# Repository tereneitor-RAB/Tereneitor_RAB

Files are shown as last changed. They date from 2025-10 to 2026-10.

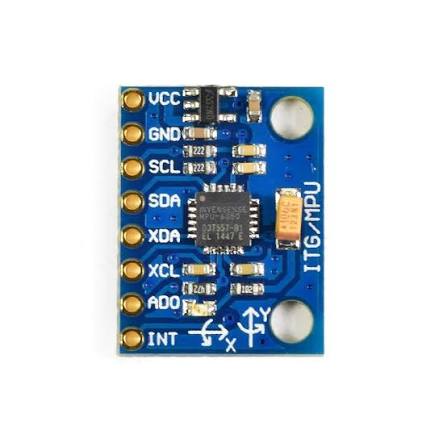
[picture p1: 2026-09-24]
Parts listo/Modulo MPU6050.jpg

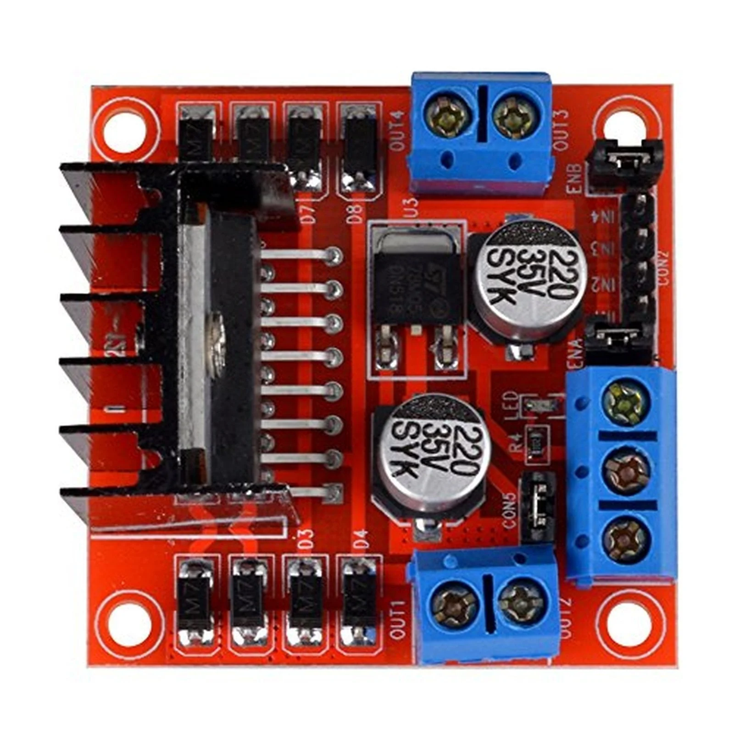
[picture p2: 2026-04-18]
Parts listo/modulo de motor.webp

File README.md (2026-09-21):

# Tereneitor_RAB| Future Engineers | Puerto Rico🚀

## Competitors of this team
- Daniel Rafael Roman Rodriguez - 19 years old
- Luis Rios Santos - 19 years old
  WhatsApp Image 2026-04-30 at 2 58 54 PM

## Robot image
WhatsApp Image 2026-09-17 at 12 14 56 AM

## Content 📘
| Folder  | content |
| -- | -- |
| [Parts listo](https://github.com/tereneitor-RAB/Tereneitor_RAB/tree/main/Parts%20listo)| [Camera 2.1V](https://github.com/tereneitor-RAB/Tereneitor_RAB/blob/main/Parts%20listo/Camera.webp) [Chasis](https://github.com/tereneitor-RAB/Tereneitor_RAB/blob/main/Parts%20listo/Chasis%20.png) [Motor DC](https://github.com/tereneitor-RAB/Tereneitor_RAB/blob/main/Parts%20listo/Motor%20DC.png) [Servo motor](https://github.com/tereneitor-RAB/Tereneitor_RAB/blob/main/Parts%20listo/Servo%20Motor.png) [Abilix engine](https://github.com/tereneitor-RAB/Tereneitor_RAB/blob/main/Parts%20listo/abilix%20engine.jpeg) [Abilix gums](https://github.com/tereneitor-RAB/Tereneitor_RAB/blob/main/Parts%20listo/abilix%20gums.jpeg) [Bateria 14V](https://github.com/tereneitor-RAB/Tereneitor_RAB/blob/main/Parts%20listo/bateria%2014v.webp) [differentiator](https://github.com/tereneitor-RAB/Tereneitor_RAB/blob/main/Parts%20listo/differentiator.jpeg) [modulo motor](https://github.com/tereneitor-RAB/Tereneitor_RAB/blob/main/Parts%20listo/modulo%20de%20motor.webp) [disminulle voltaje](https://github.com/tereneitor-RAB/Tereneitor_RAB/blob/main/Parts%20listo/modulo%20que%20disminulle%20el%20voltaje.jpg) [raspberry pi 4B](https://github.com/tereneitor-RAB/Tereneitor_RAB/blob/main/Parts%20listo/raspberry%20pi%204%20B.jpg) [touch screen](https://github.com/tereneitor-RAB/Tereneitor_RAB/blob/main/Parts%20listo/touch%20screen.jpg) [Lidar D500](https://github.com/tereneitor-RAB/Tereneitor_RAB/blob/main/Parts%20listo/Lidar%20D500.jpg)
| [Team Photos](https://github.com/tereneitor-RAB/Tereneitor_RAB/tree/main/Team%20Photos)|[foto de equipo](https://github.com/tereneitor-RAB/Tereneitor_RAB/blob/main/Team%20Photos/Foto%20de%20equipo.jpeg) [foto de equipo](https://github.com/tereneitor-RAB/Tereneitor_RAB/blob/main/Team%20Photos/foto%20del%20equipo.jpeg)
|[Vehicle Photos](https://github.com/tereneitor-RAB/Tereneitor_RAB/tree/main/photos%20of%20the%20car)|[Photos 1](https://github.com/tereneitor-RAB/Tereneitor_RAB/blob/main/photos%20of%20the%20car/Photo%201.jpg) [photos 2](https://github.com/tereneitor-RAB/Tereneitor_RAB/blob/main/photos%20of%20the%20car/photo%202.jpg) [photos 3](https://github.com/tereneitor-RAB/Tereneitor_RAB/blob/main/photos%20of%20the%20car/photo%203.jpg) [photos 4](https://github.com/tereneitor-RAB/Tereneitor_RAB/blob/main/photos%20of%20the%20car/photo%204.jpg) [photos 5](https://github.com/tereneitor-RAB/Tereneitor_RAB/blob/main/photos%20of%20the%20car/photo%205.jpg) [Photos 6](https://github.com/tereneitor-RAB/Tereneitor_RAB/blob/main/photos%20of%20the%20car/photo%206.jpg)|
|[src](https://github.com/tereneitor-RAB/Tereneitor_RAB/tree/main/src)|[Free track programming](https://github.com/tereneitor-RAB/Tereneitor_RAB/blob/main/src/Programacion%20pista%20libre.py)|
|[Videos](https://github.com/tereneitor-RAB/Tereneitor_RAB/tree/main/Videos)|[Test 1](https://github.com/tereneitor-RAB/Tereneitor_RAB/blob/main/Videos/Test%201.mp3) [Test 2](https://github.com/tereneitor-RAB/Tereneitor_RAB/blob/main/Videos/Test%202.mp3) [Test 3](https://github.com/tereneitor-RAB/Tereneitor_RAB/blob/main/Videos/Test%203.mp3)|

| project  |
| -- |
|[mount start](https://github.com/users/tereneitor-RAB/projects/1)|
|[Regional March 28](https://github.com/users/tereneitor-RAB/projects/5)|
|[regional April 18](https://github.com/users/tereneitor-RAB/projects/7)|
|[preparation for the national](https://github.com/users/tereneitor-RAB/projects/8)|
|[preparation for the California Open Championship](https://github.com/users/tereneitor-RAB/projects/10)|

------------------------------------------------------------

 #  [Our YouTube Channel](https://www.youtube.com/@Tereneitor_RedandBlue/videos)

- On our YouTube channel, we have videos of regional, national, and recent competitions to document all the processes we've undertaken over time.

------------------------------------------------------------

# WHAT IS THIS CATEGORY ABOUT❓


- This is the track for this category in 2026, on this track there are 2 modes, free mode and obstacle mode. In free mode only the robot will have to make 3 laps and stop after completing the 3 laps. In obstacle mode the robot has to make 3 laps while avoiding the obstacles and after making 3 laps it will have to parallel park.

- The obstacles are placed by the Judge and he is the one who assigns the parking spot. Both the obstacles and the parking spot are at the discretion of the Judge, so it is completely random.

- If the robot hits a wall the Judge stops counting the time and when he indicates the robot can be picked up.

- The walls in the center of the court can vary in size.

- This category may be similar to autonomous robots that are sent into space to explore planets, since they must avoid any object that gets in their way and also explore and send information about the planet.
WRO provides us with the official rules for this category of Future Engineers.

- [Official rules](https://wro-association.org/wp-content/uploads/WRO-2026-Future-Engineers-Self-Driving-Cars-General-Rules.pdf)
-------------------------------------------------------------------------

# [Explanation of the programming](https://github.com/tereneitor-RAB/Tereneitor_RAB/tree/main/src#readme)

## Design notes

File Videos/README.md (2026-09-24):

# Attached to this folder are the videos of the robot's track tests

---------------------------------------
## [youtube channel](https://www.youtube.com/@Tereneitor_RedandBlue/videos)
---------------------------------------

### **Free track tests**
- #### Test 1

https://github.com/user-attachments/assets/691180ef-8aa6-4b70-8443-ffb057dd5ace

- #### Test 2

https://github.com/user-attachments/assets/205f8fcf-265c-48af-8374-0597f4ce6e7e

- #### Test 3

https://github.com/user-attachments/assets/8cd0d115-da4b-45ae-adf6-b096099adb8a

---------------------------------------

### Obstacle course tests
- #### Test 1

https://github.com/user-attachments/assets/fc7ae0b0-fefc-44e3-b8f4-92074570e415

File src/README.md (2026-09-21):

# Attached to this folder is the robot's programming and an explanation of the programming.

# explanation of robot programming

- The robot's programming is designed to allow it to navigate the track autonomously using different sensors and control systems.

- The **D500 LiDAR** is the main sensor used to detect walls and measure the distances around the robot. The program divides the surrounding area into different zones, such as front, left, right, and diagonal sections, so the robot can determine where there is available space and make decisions when it encounters a wall.

- The **Raspberry Pi camera** is mainly used to detect red and green obstacles. The image is processed using OpenCV, and only a horizontal section of the image is analyzed to reduce unnecessary processing.

- The **steering servo** controls the direction of the robot. To prevent sudden movements, the program uses different movement speeds depending on how far the servo is from its target position. This makes the steering changes smoother.

- While moving, the robot also tries to maintain a distance of approximately **550 mm from the selected wall**. The program makes small steering corrections when the robot gets too close or too far from that wall.

- When the robot detects a wall in front of it, the program analyzes different areas on both the left and right sides before deciding which direction to take. Instead of looking at only one point, it considers the side, diagonal, and near-front areas.

- Every time a new turn begins, the program increases the turn counter. The limit is set to **12 turns**. Once the robot reaches the 12th turn, it stops the motor, centers the servo, and shuts down the steering system.
The program also includes an **emergency reverse system**. If the LiDAR detects that a wall is too close, the robot stops, reverses, and checks the available space again before continuing.

- The robot starts after the start button is pressed. While waiting, the green LED stays on to indicate that the system is ready. Once the button is pressed, the motor starts moving and the program enters its main navigation loop.

- During the run, the program displays the camera feed and a **360° LiDAR radar**, along with the front, left, and right distances, detected color, number of turns completed, and the current servo position.

- Overall, the program combines the **LiDAR for navigation**, the **camera for color-based obstacle detection**, and the **servo and motor for movement**. This allows the robot to make decisions while navigating the track without manual control.

---------------------------------------------------------------------------

# Operating System Installation – Raspberry Pi 4B

Before starting the project, the Raspberry Pi 4B needs an operating system. For this project, **Raspberry Pi OS** is installed on a microSD card using **Raspberry Pi Imager**.

## 1. Download Raspberry Pi Imager

Download and install **Raspberry Pi Imager** on a computer from the official Raspberry Pi website:

[**Download Raspberry Pi Imager**](https://www.raspberrypi.com/software/)

Then connect the microSD card to the computer using a card reader.

## 2. Select the Raspberry Pi

Open Raspberry Pi Imager and select:

* **Device:** Raspberry Pi 4
* **Operating System:** Raspberry Pi OS
* **Storage:** The connected microSD card

> [!IMPORTANT]
> The microSD card will be erased during the installation. Make sure the correct card is selected.

## 3. Configure the System

Before writing the operating system, Raspberry Pi Imager allows you to configure some basic settings, such as:

* Username and password
* Wi-Fi connection
* Time zone
* Keyboard layout
* Hostname

These settings make the Raspberry Pi ready to use after the first boot.

## 4. Install the Operating System

After checking the configuration:

1. Click **Next** or **Write**.
2. Confirm that the microSD card can be erased.
3. Wait while Raspberry Pi Imager writes the operating system.
4. Wait for the verification process to finish.

This may take several minutes.

## 5. Start the Raspberry Pi

When the installation is complete:

1. Safely eject the microSD card.
2. Insert it into the Raspberry Pi 4B.
3. Connect the monitor, keyboard, and mouse if needed.
4. Connect the power supply.
5. Wait for Raspberry Pi OS to start.

Complete any remaining initial configuration.

## 6. Update the System

Open the terminal and run:

```bash
sudo apt update
sudo apt full-upgrade -y
```

Then restart the Raspberry Pi:

```bash
sudo reboot
```

## 7. Verify the Installation

To check the operating system, run:

```bash
cat /etc/os-release
```

If the Raspberry Pi OS information is displayed correctly, the installation is complete.

----------------------------------------------------------------------------

# Required Libraries Installation

After installing Raspberry Pi OS, the next step is to install the Python libraries required by the robot.

## 1. Update the System

First, update the package list:

```bash
sudo apt update
sudo apt full-upgrade -y
```

## 2. Install Python and Basic Tools

Install Python and the required development tools:

```bash
sudo apt install -y python3 python3-pip python3-dev
```

## 3. Install OpenCV

OpenCV is used for image processing and detecting colors and objects with the Raspberry Pi Camera.

```bash
sudo apt install -y python3-opencv
```

Verify the installation:

```bash
python3 -c "import cv2; print(cv2.__version__)"
```

## 4. Install Picamera2

Picamera2 is used to control the Raspberry Pi Camera.

```bash
sudo apt install -y python3-picamera2
```

Verify the installation:

```bash
python3 -c "from picamera2 import Picamera2; print('Picamera2 OK')"
```

## 5. Install GPIO Libraries

The GPIO pins are used to control the button, LEDs, motor driver, and servo.

Install RPi.GPIO:

```bash
sudo apt install -y python3-rpi.gpio
```

If the project uses GPIO Zero, it can also be installed with:

```bash
sudo apt install -y python3-gpiozero
```

## 6. Install PySerial

PySerial is used for serial communication between the Raspberry Pi and the LiDAR D500.

```bash
sudo apt install -y python3-serial
```

Verify the installation:

```bash
python3 -c "import serial; print('PySerial OK')"
```

## 7. Install NumPy

NumPy is used by OpenCV and other parts of the vision system for numerical and image data processing.

```bash
sudo apt install -y python3-numpy
```

Verify the installation:

```bash
python3 -c "import numpy; print(numpy.__version__)"
```

## 8. Install All Main Libraries

The main libraries used by the robot can also be installed together:

```bash
sudo apt install -y python3-opencv python3-picamera2 python3-rpi.gpio python3-gpiozero python3-serial python3-numpy
```

## 9. Test the Main Libraries

Run the following command to check that the main Python libraries can be imported:

```bash
python3 -c "import cv2, serial, numpy; from picamera2 import Picamera2; import RPi.GPIO; print('All main libraries installed successfully')"
```

If the terminal displays:

```text
All main libraries installed successfully
```

the main software dependencies are ready.

- # After downloading the operating system and libraries on the Raspberry Pi 4B, it would be 100% ready to run the programming explained above.

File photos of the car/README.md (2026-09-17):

# Attached to this folder are photos of the robot from different angles.

WhatsApp Image 2026-09-17 at 12 14 56 AM

| Side on which the photo was taken | Photos |
| -- | -- |
| Frontal  | |
| Left side  | |
| Right back | |
| Tracer | |
|  Superior  | |
| Later | |

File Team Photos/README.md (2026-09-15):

# Attached to this folder are photos of the team members
- **photo 1**
WhatsApp Image 2026-04-30 at 2 58 54 PM

- **photo 2**
foto del equipo

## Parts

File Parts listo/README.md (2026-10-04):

# Attached to this folder is the list of parts used by our robot

## 📦 Parts List

|  # | Component | Quantity | Description / Function |
| -: | --- | ---: | --- |
|  1 | Raspberry Pi 4 Model B | 1 | Main computer and control system of the robot |
|  2 | Raspberry Pi Camera V2 | 1 | Vision system used for color and obstacle detection |
|  3 | LDROBOT D500 LiDAR | 1 | Distance sensor used to detect walls, obstacles, and openings |
|  4 | L298N Motor Driver | 1 | Controls the DC motors |
|  5 | Servo Motor | 1 | Controls the steering mechanism |
|  6 | DC Motors | 1 | Provides movement and propulsion |
|  7 | Wheels | 4 | Allows the robot to move around the competition field |
|  8 | Robot Chassis | 1 | Main structural platform of the robot |
|  9 | Battery | 1 | Provides power to the robot's electrical system |
| 10 | Push Button | 1 | Used to start the robot |
| 11 | Green LED | 1 | Indicates that the robot is ready to start |
| 12 | Jumper Wires / Cables  | 16 | Used for electrical and signal connections |
| 13 | Screws and nuts | 56 | Used to mount and secure the components |
| 14 | Camera Mount | 1 | Secures the camera to the robot |
| 15 | thread separators | 12 | to separate and join the parts of the chassis |
| 16 | publisher | 1 | to start programming |
| 17 | MPU 6050 | 1 | Monitor the turns |

## 💲 price of materials purchased

| # | Component | Quantity | Estimated Unit Price (USD) |
|---|---|---|---|
| 1 | Raspberry Pi 4 Model B 4GB | 1 | $75.00 |
| 2 | Raspberry Pi Camera V2 | 1 | $16.50 |
| 3 | LDROBOT D500 LiDAR | 1 | $69.00 
| 4 | L298N Motor Driver | 1 | $5.00 |
| 5 | Servo Motor | 1 | $8.00 |
| 6 | DC Motors | 1 set | $15.00 |
| 7 | Wheels | 4 | $12.00 |
| 8 | Robot Chassis | 1 | $25.00 |
| 9 | Battery | 1 | $30.00 |
| 10 | Push Button | 1 | $0.50 |
| 11 | Green LED | 1 | $0.25 |
| 12 | Jumper Wires / Cables | 16 | $2.00 |
| 13 | Screws and Nuts | 56 | $6.00 |
| 14 | Camera Mount | 1 | $8.00 |
| 15 | Thread Separators | 12 | $5.00 |
| 16 | Publisher / Programming Software | 1 | $0.00 |
| 17 | MPU6050 | 1 | $4.00 |
| 18 | Blue PLA Filament, 1 kg | 1 | $16.90 |
| 19 | Red PLA Filament, 1 kg | 1 | $16.90 |
> **Estimated total project cost: $314.55 USD**

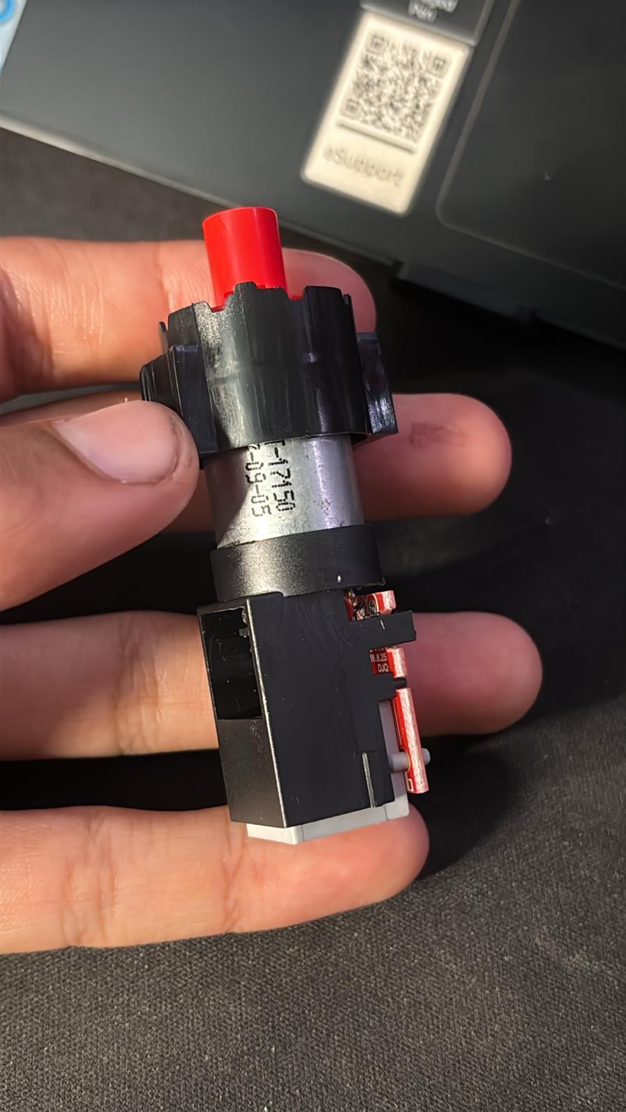
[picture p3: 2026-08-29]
Parts listo/abilix engine.jpeg

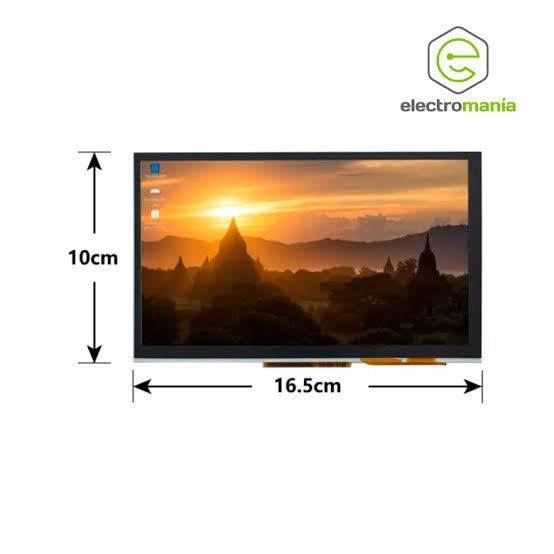
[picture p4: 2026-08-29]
Parts listo/touch screen.jpg

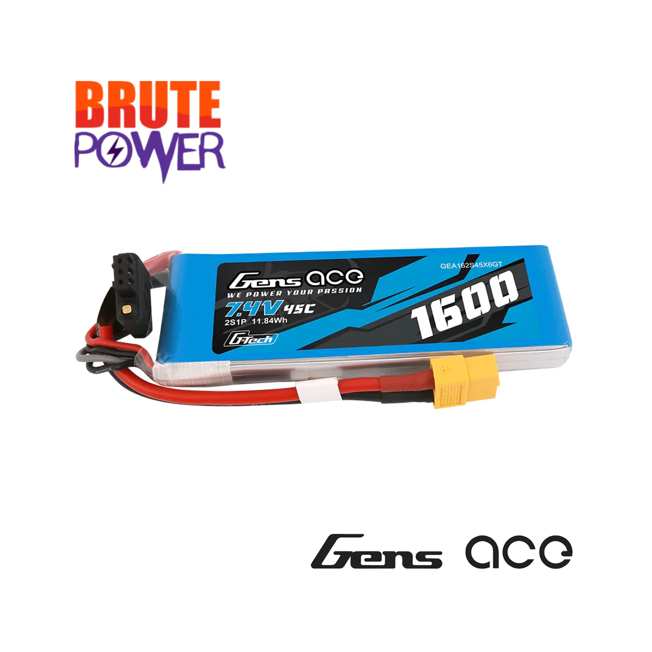
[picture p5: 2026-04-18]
Parts listo/bateria 14v.webp

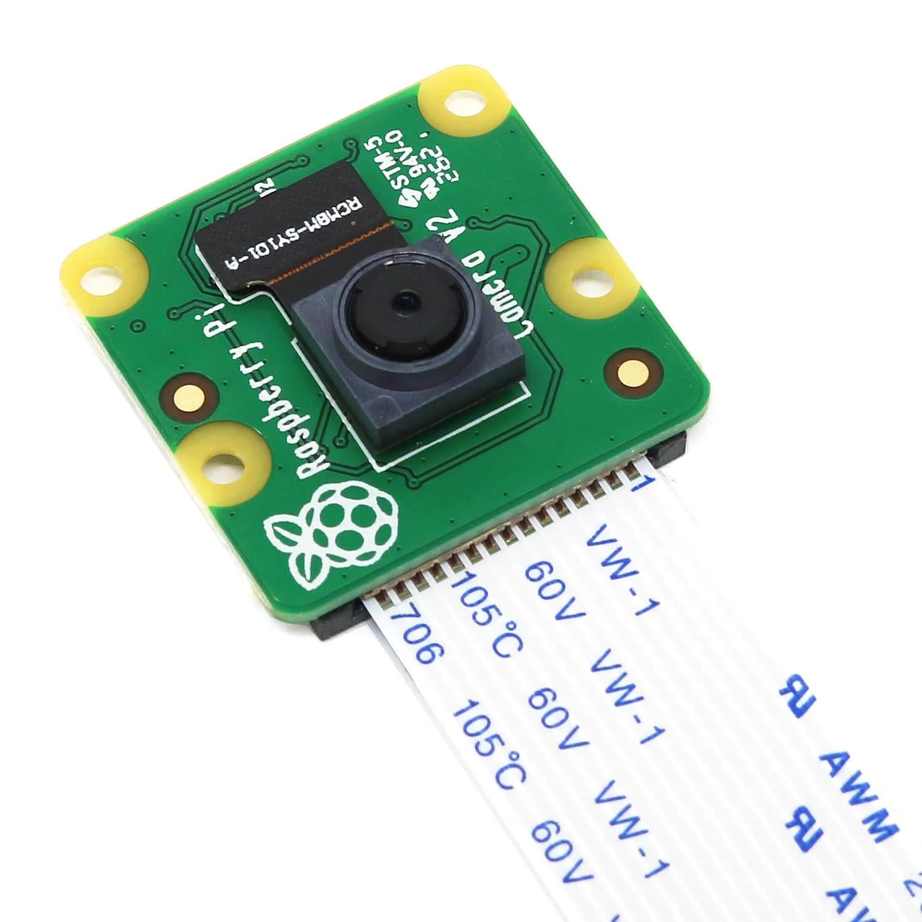
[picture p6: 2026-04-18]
Parts listo/Camera.webp

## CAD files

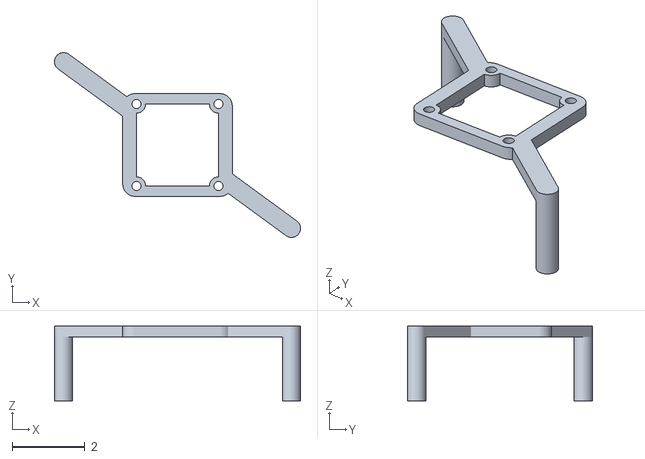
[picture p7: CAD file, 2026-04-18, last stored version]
3D Models listo/avanico.stl
6.75 x 5.07 x 2.05

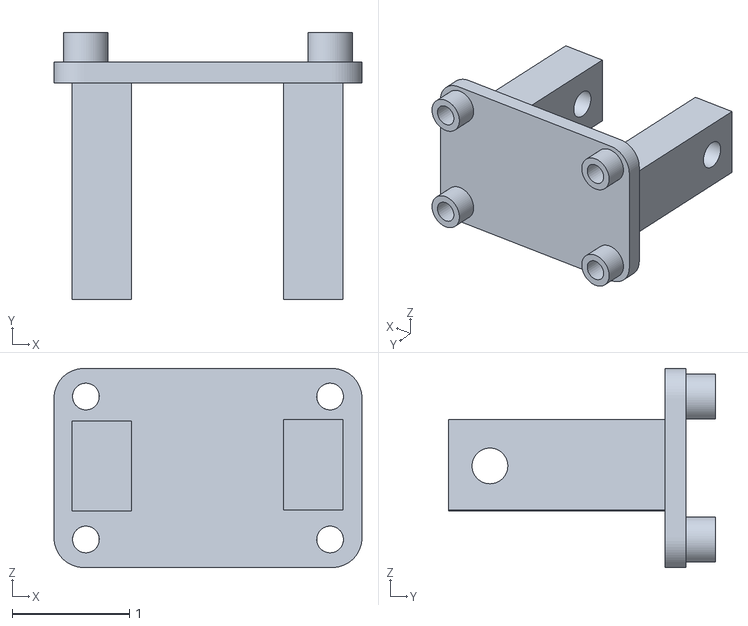
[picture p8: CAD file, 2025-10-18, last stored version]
3D Models/Frame/camera adapter.stl
2.63 x 2.28 x 1.70

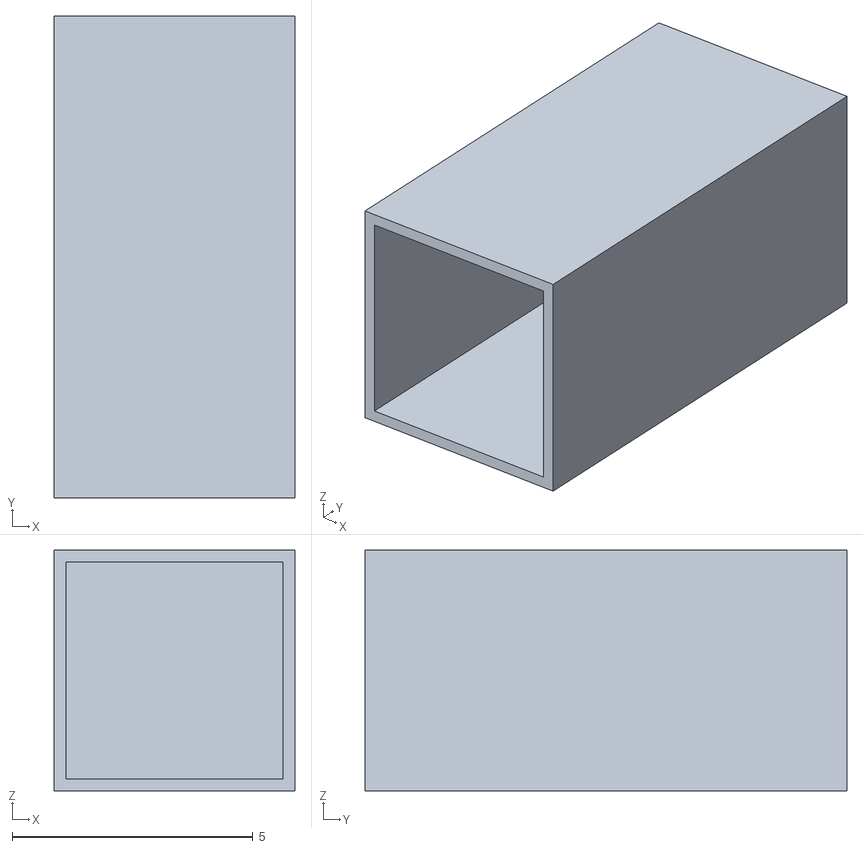
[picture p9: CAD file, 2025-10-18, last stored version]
3D Models/Traffic signs.stl
5.00 x 10.0 x 5.00

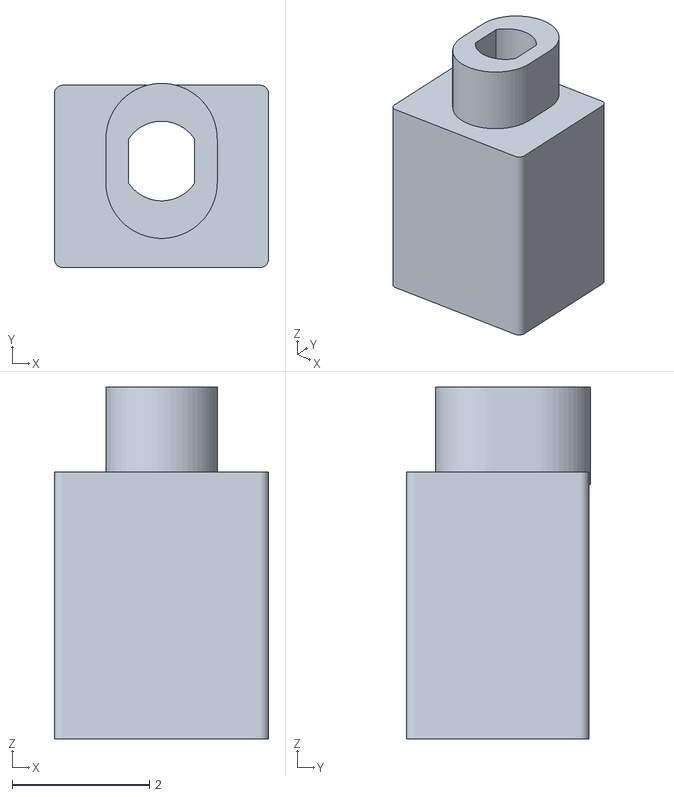
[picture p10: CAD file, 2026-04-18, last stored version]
3D Models listo/base de motor.stl
3.12 x 2.68 x 5.13

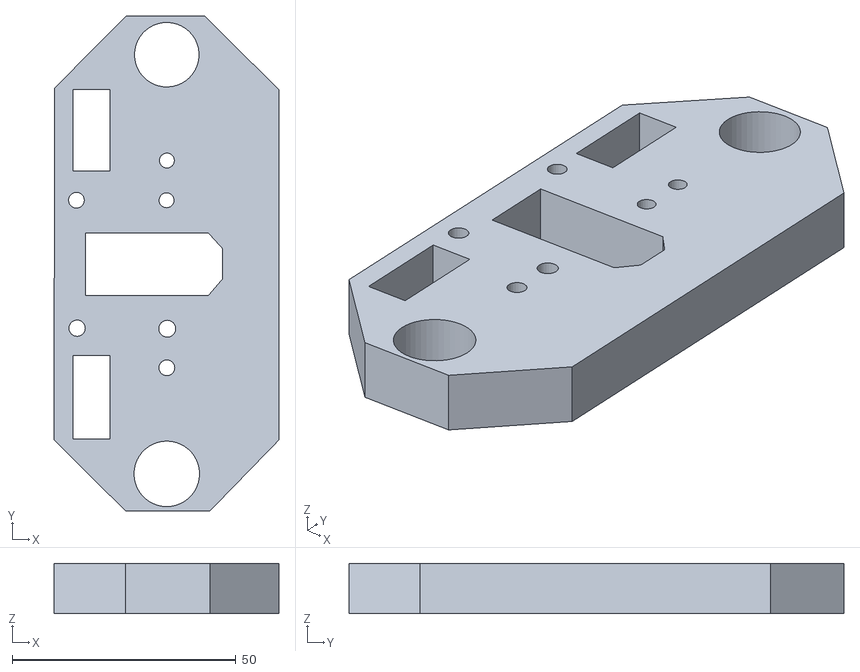
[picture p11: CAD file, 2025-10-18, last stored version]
3D Models/Frame/Model 7.stl
50.3 x 110.7 x 11.2

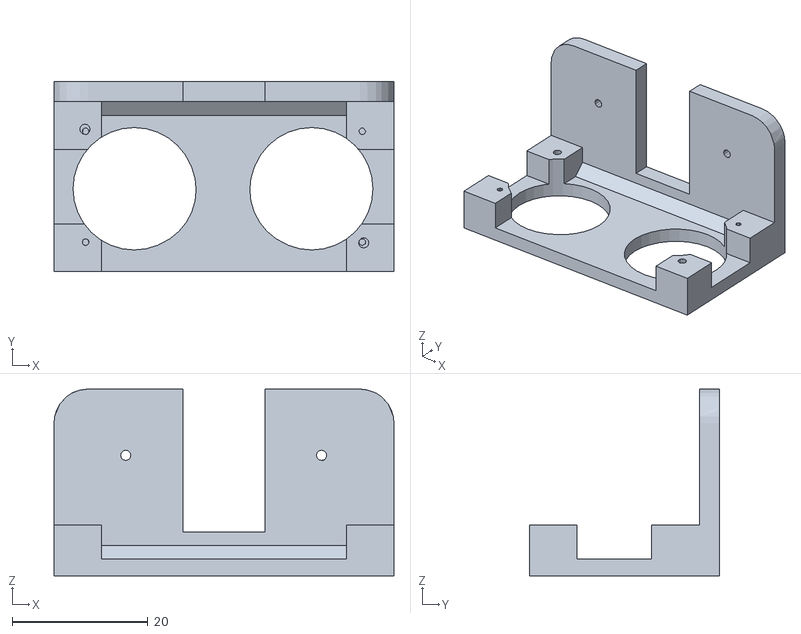
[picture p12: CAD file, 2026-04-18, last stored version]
3D Models listo/Front_ultrasonic_sensor_base.stl
50.0 x 28.0 x 27.5

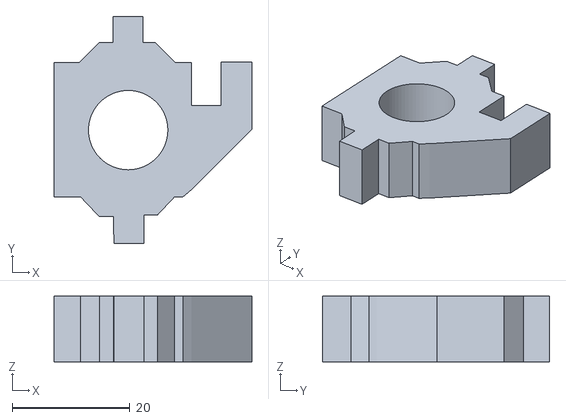
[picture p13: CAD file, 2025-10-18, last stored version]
3D Models/Frame/Model 1.stl
33.6 x 38.6 x 11.2

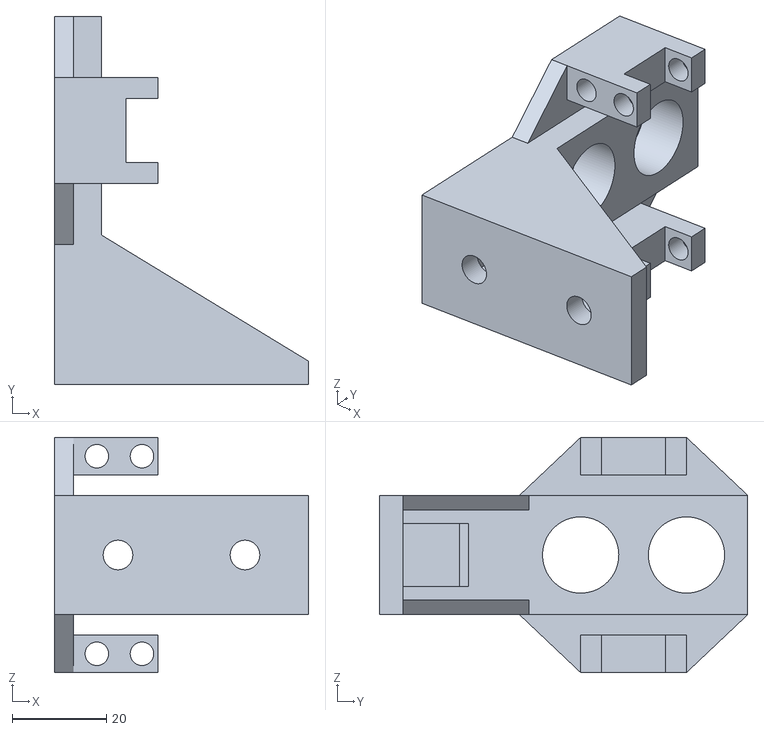
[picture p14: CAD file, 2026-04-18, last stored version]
3D Models listo/Side_Ultrasonic_Sensor_Base.stl
54.0 x 78.3 x 50.0

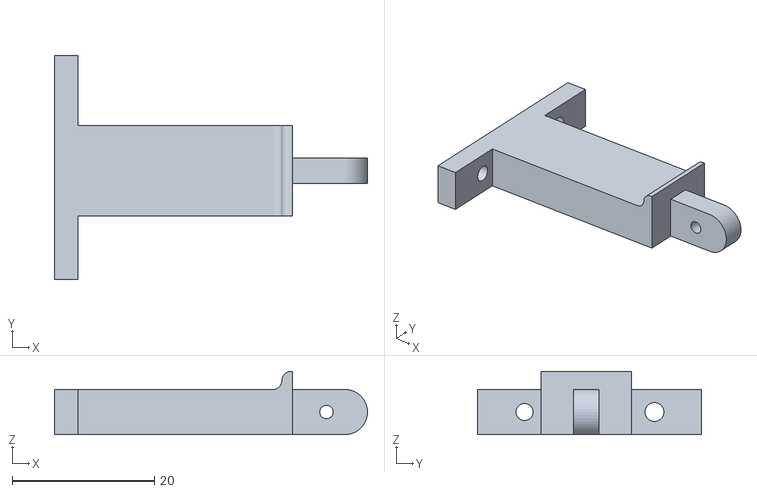
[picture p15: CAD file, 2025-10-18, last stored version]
3D Models/Frame/Model 12.stl
44.1 x 31.5 x 8.89

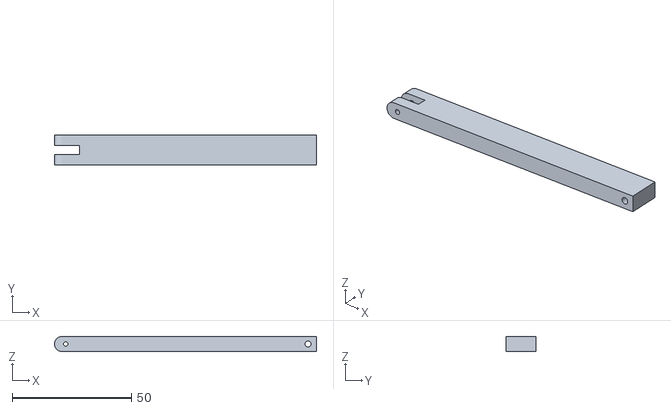
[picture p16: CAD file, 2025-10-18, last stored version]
3D Models/Frame/Model 6.stl
110.0 x 12.7 x 6.35

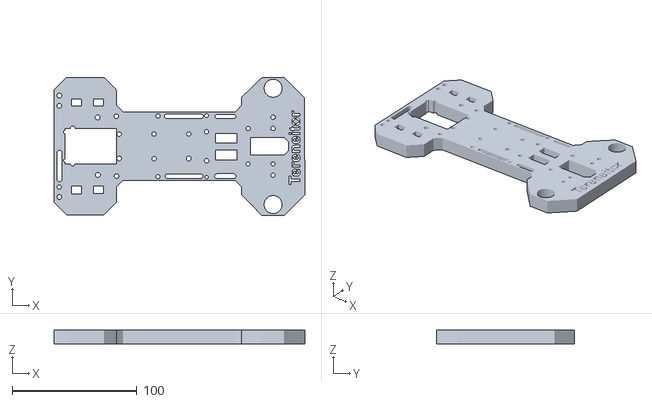
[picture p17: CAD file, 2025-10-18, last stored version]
3D Models/Frame/Model 8.stl
201.3 x 110.9 x 11.2

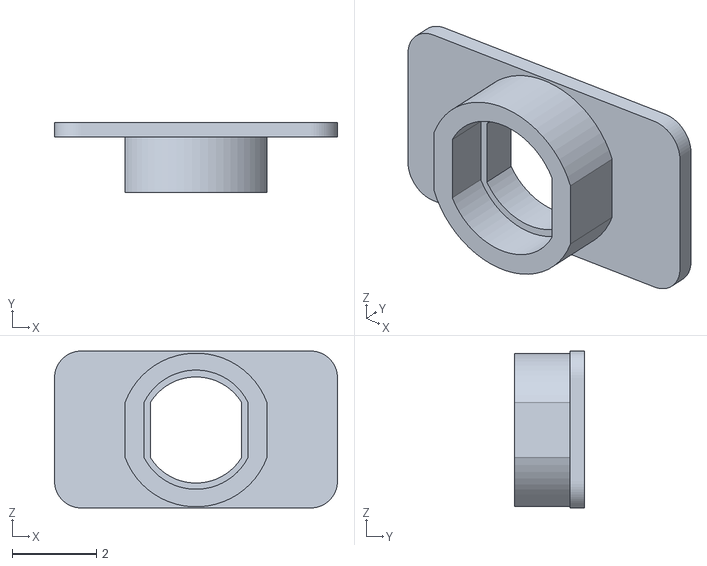
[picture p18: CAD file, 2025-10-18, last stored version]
3D Models/Frame/motor base.stl
6.72 x 1.67 x 3.73

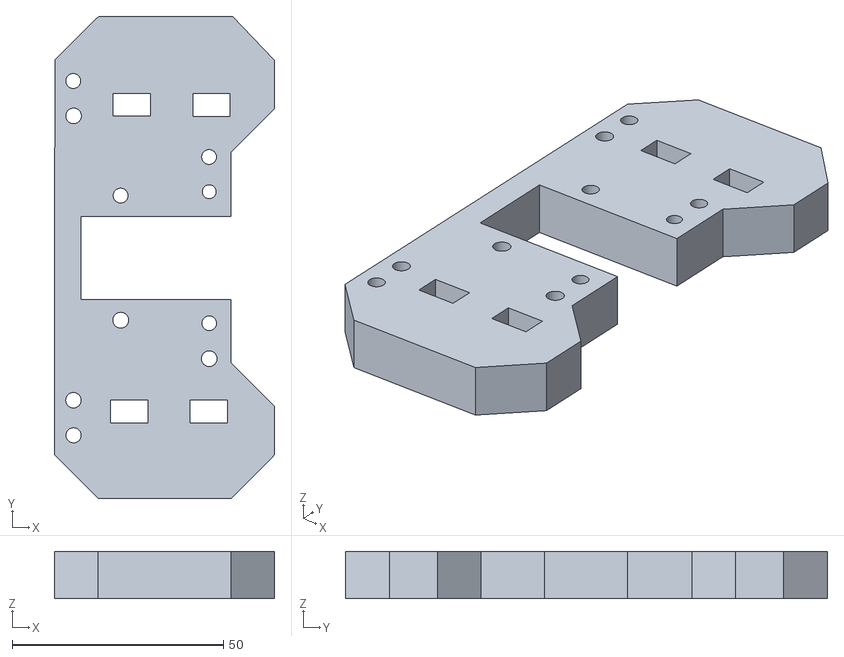
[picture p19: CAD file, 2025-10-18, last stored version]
3D Models/Frame/Model 11.stl
52.1 x 114.0 x 11.2

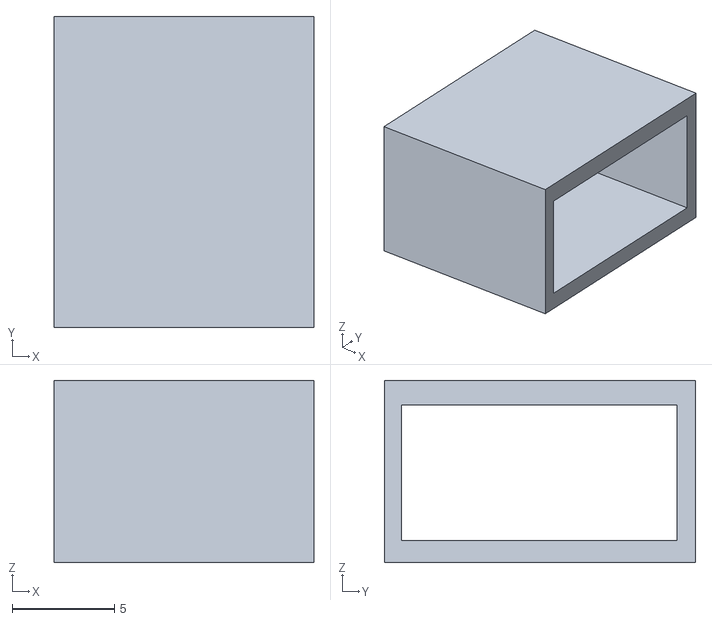
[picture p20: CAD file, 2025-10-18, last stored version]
3D Models/Frame/Model 5.stl
12.7 x 15.2 x 8.90

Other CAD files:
3D Models/Frame/Model 4.stl
3D Models/Frame/Model 2.stl
3D Models/Frame/Model 3.stl
3D Models/Frame/Model 10.stl
3D Models/Frame/Model 9.stl

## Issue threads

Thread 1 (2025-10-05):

presentation of the group Day #1

tereneitor-RAB, 2025-10-05:
Our group is made up of **Daniel, Luis, and Jason**, three students passionate about engineering and technology. We participated in the **WRO Future Engineers** competition with the goal of applying our knowledge, strengthening our skills, and developing an innovative project. Through this work, we seek to proudly represent Puerto Rico and demonstrate our commitment to advancing educational robotics.

Today, October 5, 2025, we will begin assembling a new robot for the WRO Future Engineers competition in 2026, **in which we aim to build upon our experience from 2024, when we competed in the same category and reached the World Championships in Turkey, and once again showcase our skills and innovation with this new robot.**

tereneitor-RAB, 2025-10-05:
**Today we're deciding what kind of robot we want to build**
one that uses sensors or one that works with external cameras. While we make this decision, I, Daniel Roman, will be in charge of documenting everything we do today.

tereneitor-RAB, 2025-10-05:
**After mentioning the weaknesses of each of the options we had, we decided to have the car equipped with a camera, since we can find another solution for the blind spots later on. Another thing is that we have to decide what type of camera and what motherboard runs the image and programming appropriate for this project. As a group, we decided that the car will be equipped with a camera for now.**

_For the moment, we will not work on anything else. The task of each of us is to find what type of chassis we want. We will look for ideas on the Internet and kits that exist and we will let ourselves be guided by those types of chassis. But something that we will have in mind is that the type of chassis must be compatible with a differentiator and front turning mechanism, since the rules emphasize those specifications._

Closed 2025-10-05.

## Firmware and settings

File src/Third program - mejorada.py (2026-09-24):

from picamera2 import Picamera2
import cv2
import numpy as np
import time
import RPi.GPIO as GPIO
import serial
import threading
import math
import os
import smbus2

os.environ["DISPLAY"] = ":0"

# ============================================================
# GPIO
# ============================================================

GPIO.setmode(GPIO.BCM)
GPIO.setwarnings(False)

BOTON = 16
GPIO.setup(BOTON, GPIO.IN, pull_up_down=GPIO.PUD_UP)

# SERVO 180Ã‚Â°
SERVO_PIN = 18
GPIO.setup(SERVO_PIN, GPIO.OUT)

# LED VERDE - ROBOT LISTO
LED_VERDE = 21
GPIO.setup(LED_VERDE, GPIO.OUT)
GPIO.output(LED_VERDE, GPIO.LOW)

# MOTOR
MOTOR_IN3 = 17
MOTOR_IN4 = 27
MOTOR_EN = 22

GPIO.setup(MOTOR_IN3, GPIO.OUT)
GPIO.setup(MOTOR_IN4, GPIO.OUT)
GPIO.setup(MOTOR_EN, GPIO.OUT)


# ============================================================
# SERVO 180Ã‚Â°
# ============================================================

SERVO_CENTRO = 84
SERVO_IZQUIERDA = 65
SERVO_DERECHA = 115

SERVO_MIN = 60
SERVO_MAX = 120

INVERTIR_SERVO = False

servo_angulo_actual = SERVO_CENTRO
servo_objetivo = SERVO_CENTRO

servo_pwm = GPIO.PWM(SERVO_PIN, 50)
servo_pwm.start(0)

servo_activo = False
ultimo_movimiento_servo = 0.0


def activar_servo():

    global servo_activo
    global ultimo_movimiento_servo

    if not servo_activo:

        servo_pwm.ChangeDutyCycle(
            2.5 + (SERVO_CENTRO / 180.0) * 10.0
        )

        servo_activo = True
        ultimo_movimiento_servo = time.monotonic()

        time.sleep(0.15)


def desactivar_servo():

    global servo_activo

    if servo_activo:
        servo_pwm.ChangeDutyCycle(0)
        servo_activo = False


# ------------------------------------------------------------
# CONTROL DE SERVO
# ------------------------------------------------------------

SERVO_PASO_RAPIDO = 4.0
SERVO_PASO_MEDIO = 2.5
SERVO_PASO_FIN = 1.2
SERVO_INTERVALO = 0.015


def establecer_objetivo_servo(angulo):

    global servo_objetivo

    servo_objetivo = max(
        SERVO_MIN,
        min(SERVO_MAX, float(angulo))
    )


def actualizar_servo():

    global servo_angulo_actual
    global ultimo_movimiento_servo

    if not servo_activo:
        return

    ahora = time.monotonic()

    if ahora - ultimo_movimiento_servo < SERVO_INTERVALO:
        return

    diferencia = servo_objetivo - servo_angulo_actual
    distancia = abs(diferencia)

    if distancia < 0.6:

        servo_angulo_actual = servo_objetivo

    else:

        if distancia > 18:
            paso = SERVO_PASO_RAPIDO

        elif distancia > 7:
            paso = SERVO_PASO_MEDIO

        else:
            paso = SERVO_PASO_FIN

        if diferencia > 0:

            servo_angulo_actual += min(
                paso,
                diferencia
            )

        else:

            servo_angulo_actual -= min(
                paso,
                -diferencia
            )

    servo_angulo_actual = max(
        SERVO_MIN,
        min(SERVO_MAX, servo_angulo_actual)
    )

    salida = servo_angulo_actual

    if INVERTIR_SERVO:
        salida = 180 - salida

    duty = 2.5 + (salida / 180.0) * 10.0

    servo_pwm.ChangeDutyCycle(duty)

    ultimo_movimiento_servo = ahora


def mover_servo_suave(angulo):

    establecer_objetivo_servo(angulo)


# ============================================================
# MOTOR
# ============================================================

motor_pwm = GPIO.PWM(
    MOTOR_EN,
    1000
)

motor_pwm.start(0)

VELOCIDAD = 89


def motor_avanzar(velocidad=VELOCIDAD):

    GPIO.output(
        MOTOR_IN3,
        GPIO.HIGH
    )

    GPIO.output(
        MOTOR_IN4,
        GPIO.LOW
    )

    motor_pwm.ChangeDutyCycle(
        velocidad
    )


def motor_retroceder(velocidad=90):

    GPIO.output(
        MOTOR_IN3,
        GPIO.LOW
    )

    GPIO.output(
        MOTOR_IN4,
        GPIO.HIGH
    )

    motor_pwm.ChangeDutyCycle(
        velocidad
    )


def motor_parar():

    motor_pwm.ChangeDutyCycle(0)

    GPIO.output(
        MOTOR_IN3,
        GPIO.LOW
    )

    GPIO.output(
        MOTOR_IN4,
        GPIO.LOW
    )


# ============================================================
# LIDAR D500
# ============================================================

PUERTO_LIDAR = "/dev/serial0"
BAUDRATE = 230400

try:

    lidar = serial.Serial(
        PUERTO_LIDAR,
        BAUDRATE,
        timeout=0.05
    )

    print(
        "LIDAR conectado:",
        PUERTO_LIDAR
    )

except Exception as e:

    print(
        "ERROR LIDAR:",
        e
    )

    lidar = None


puntos_lidar = []

lock_lidar = threading.Lock()


# ============================================================
# CRC-8
# ============================================================

def crc8(data):

    crc = 0

    for byte in data:

        crc ^= byte

        for _ in range(8):

            if crc & 0x80:

                crc = (
                    (crc << 1)
                    ^ 0x4D
                ) & 0xFF

            else:

                crc = (
                    crc << 1
                ) & 0xFF

    return crc


# ============================================================
# LECTURA LIDAR
# ============================================================
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

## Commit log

2026-04-30 Add category details for 2026 track in README
    Added a section explaining the category details for the 2026 track, including modes and rules.
2026-04-30 Update README with new image and track information
    Added an image and clarified the category track details for 2026.
2026-05-11 Update README with new image and category details
    Added an image and updated the description of the category for the 2026 track.
2026-08-29 Update README to include Camera 2.1V link
    Added link to Camera 2.1V image in the README.
2026-09-06 Add Lidar D500 to Parts list
2026-09-12 Update README with Free track programming link
    Added link to Free track programming in the README.
2026-09-14 Update README with links to track test videos
    Added links to free track test videos.
2026-09-16 Update DC Motors quantity in README.md
2026-09-17 Expand README with robot programming details
    Added detailed explanations of the robot's programming, including sensor usage, navigation strategies, and system functionalities.
2026-09-21 Remove Raspberry Pi OS installation instructions
    Removed the section on operating system installation for Raspberry Pi 4B, including steps for downloading, configuring, and verifying the installation.
2026-09-24 Update print statement from 'Hello' to 'Goodbye'
2026-09-24 Update fmt.Println message from 'Hello' to 'Goodbye'
2026-10-04 Update BOM section title to price of materials purchased
2026-10-04 Update DC Motors price from $20 to $15
